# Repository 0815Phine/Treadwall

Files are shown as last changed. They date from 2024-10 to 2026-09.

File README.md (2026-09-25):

# Treadwall

A Bpod-controlled behavioral rig for head-fixed mice: the animal runs on a
treadmill while two motorized silicone "walls" move laterally to deliver
tactile stimuli that are either synchronized to running speed or driven by an
experimental protocol. A central Python GUI ([`code/treadwallGUI.py`](code/treadwallGUI.py))
launches and coordinates a whole session: dual-camera video, the Bpod state
machine, WaveSurfer data acquisition, and timestamped notes uploaded to RSpace.

<p align="center">
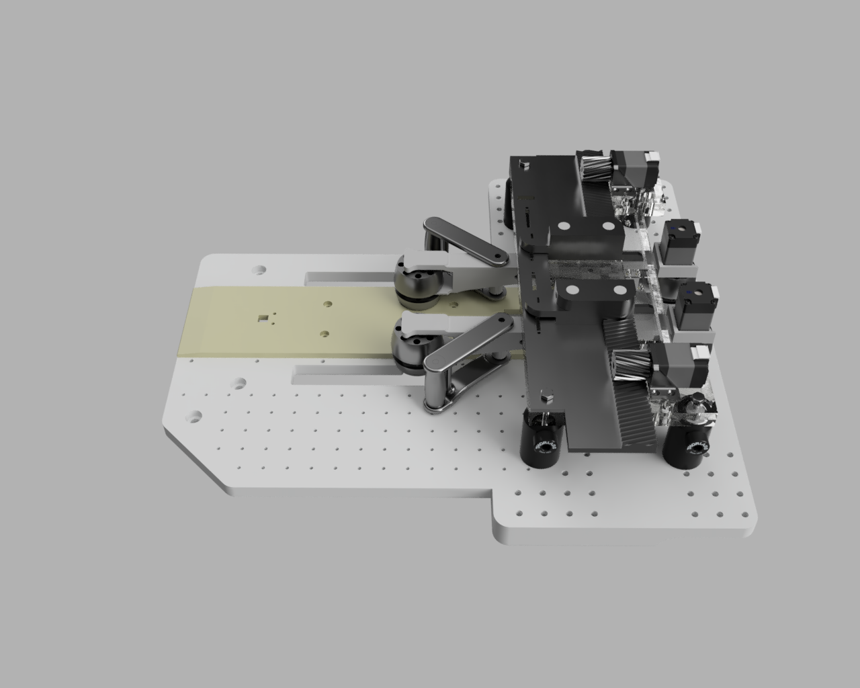
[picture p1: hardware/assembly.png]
  
</p>

This repository holds everything needed to **rebuild and run** the setup: hardware
files (3D-print STLs, laser-cut SVGs, PCB gerbers, parts lists) under
[`hardware/`](hardware/) (see the [hardware README](hardware/README.md)) and all control software under [`code/`](code/) (see the
[code README](code/README.md)).

### Repository structure

```
Treadwall/
├── hardware/            # build files + parts lists, one folder per component
│   ├── treadmillmain/       running wheel / treadmill
│   ├── treadwallmain/       moving-wall assembly (STLs, SVGs, assembly videos)
│   ├── wallsynchronizer/    Arduino + PCB that syncs wall motion to running speed
│   ├── wallmover/           PCB that drives wall position from Bpod
│   ├── circuitbox/          enclosure electronics
│   ├── assembly.png         setup overview (above)
│   └── connections_overview.png
└── code/                # see code/README.md
    ├── treadwallGUI.py      central session-launcher GUI
    ├── startsession.bat     double-click to launch
    ├── src/                 utility + GUI-helper scripts, camera, Arduino sketches
    ├── protocols/           the five Bpod experiment protocols
    ├── parameters/          central config (treadwall_config.json) + device settings
    └── dependencies/        vendored submodules (Bpod, WaveSurfer, IEECRSpace, …)
    └── gui_screenshot.png   GUI while running (see below)
```

### Getting started
1. Clone with submodules: `git clone --recurse-submodules https://github.com/0815Phine/Treadwall.git`
   (or `git submodule update --init --recursive` after a plain clone).
2. Create the `treadwall` conda environment (see [Python environment](#python-environment)).
3. Set up the IEECRSpace submodule once (see [Software Dependencies](#software-dependencies)).
4. Install **ffmpeg** and put it on `PATH` (see [Python environment](#python-environment)).
5. Edit the paths in [`code/parameters/treadwall_config.json`](code/parameters/treadwall_config.json)
   for your machine (MATLAB/Python executables, data + IPC directories).
6. Open Matlab and add the paths of wavesurfer and bpod (both found under [`code/dependencies`](code/dependencies)).
7. Launch Bpod by typing Bpod in the Matlab console and set it up (see [Bpod setup](#bpod-setup))
8. Launch a session by double-clicking [`code/startsession.bat`](code/startsession.bat)
   — see [Running a Session](#running-a-session).

## Bpod System
Control of the system is done with the Bpod System. All used modules are controlled by a 'state machine' ([sanworks.io](https://sanworks.io/shop/viewproduct?productID=1036)).

Modules used:
| Module | Link | Functionality |
| :---: | :---: | :---: |
| Analog Output Module | [sanworks.io](https://sanworks.io/shop/viewproduct?productID=1038) | loaded with Waveplayer Firmware, can play analog signals, controls lateral movement of walls |
| Analog Input Module | [sanworks.io](https://sanworks.io/shop/viewproduct?productID=1037) | reads analog signals, used for zone transition in predictable paradigm |
| Rotary Encoder Module V2 | [sanworks.io](https://sanworks.io/shop/viewproduct?productID=1034) | connected directly to the rotary encoder, provides power and sends speed information to analog input module, loaded with modified firmware ([github.com](https://github.com/0815Phine/Bpod_RotaryEncoder_Firmware)) |

For further modules see [sanworks.io/products](https://sanworks.io/shop/products.php).

### Bpod setup
On **first start** Bpod has to be configured to run properly. Therefore start the Bpod GUI by typing ```Bpod``` in the Matlab console.
All modules have to be coupled with the correct COM of your system (also check the Arduino COM in the main treadwall_config.json).
You additionally have to configure the data paths once. Use the same 'Data Root' as defined in the config file (this is not strictly needed but in case of falling back to this, it is good to match).
The 'Protocols' directory should point to [`code/protocols`](code/protocols).

## Software Dependencies
| Tool | Version / build | Purpose |
| :--- | :--- | :--- |
| MATLAB | R2024a | Runs Bpod (`Bpod_Gen2`) + WaveSurfer |
| WaveSurfer | 1.0.x (see `code/dependencies/Wavesurfer`) | Synchronized data acquisition (needs a DAQ) |
| ffmpeg ([ffmpeg.org](https://ffmpeg.org/)) | gyan.dev **full** build, on `PATH` | Live H.264 encoding in `videoacquisition.py`; full build needed for `h264_nvenc` (GPU) |
| Anaconda / Python | Python 3.11 | Runs the GUI + camera scripts (`treadwall` env) |
| Basler pylon Camera Software Suite | matching pypylon 4.1 | Camera drivers/runtime for `pypylon` |
| NI-DAQmx driver + NI DAQ device | — | WaveSurfer acquisition + TTL sync (the "DAQ-Box") |
| Pololu Tic software (Tic Control Center) | — | Configure the Wall Mover / Wall Synchronizer stepper controllers |
| Arduino IDE | 2.x ([arduino.cc](https://www.arduino.cc/en/software)) | Flash/modify the Wall-Synchronizer Arduino + rotary-encoder firmware |
| git | ≥ 2.x | Clone the repo with `--recurse-submodules` |
| PsychToolbox (*optional*) | — | **Not needed for Treadwall's default setup.** Bpod only requires it for legacy MATLAB (r2019a or older), displaying video/sound stimuli on the PC, or the legacy Bonsai UDP/TCP link — none of which Treadwall uses. Safe to keep installed if you already have it. |

### Submodules
External code is vendored as **git submodules** under [code/dependencies/](code/dependencies/).
Clone with `git clone --recurse-submodules`, or run `git submodule update --init --recursive`
after cloning.

| Submodule | Source | Notes |
| :--- | :--- | :--- |
| `Bpod_Gen2` | [sanworks/Bpod_Gen2](https://github.com/sanworks/Bpod_Gen2) @ `master` (pinned `8e5b008`, v1.9.0) | Stock Bpod control framework. |
| `Bpod_RotaryEncoder_Firmware` | [0815Phine/Bpod_RotaryEncoder_Firmware](https://github.com/0815Phine/Bpod_RotaryEncoder_Firmware) | Modified rotary-encoder module firmware (needed for the *predictable* experiments). |
| `Wavesurfer` | [JaneliaSciComp/Wavesurfer](https://github.com/JaneliaSciComp/Wavesurfer) | WaveSurfer app for synchronized data acquisition. |
| `IEECRSpace` | [IEECR-BeckGroup/IEECRSpace](https://github.com/IEECR-BeckGroup/IEECRSpace) | RSpace integration; `treadwallGUI.py` adds `IEECRSpace/src` to `sys.path` and imports `rspace`. |

**IEECRSpace must be set up once before the GUI's RSpace features work.** The submodule is a
self-contained app that installs itself on first launch. If you haven't done this yet, run its
first-time setup — on Windows double-click
[`code/dependencies/IEECRSpace/IEECRSpace_Launcher.bat`](code/dependencies/IEECRSpace/) (the first
launch downloads its own private Python + dependencies, so it needs an internet connection) — and
then paste your RSpace API key into the app's **Settings** tab. See the
[IEECRSpace README](code/dependencies/IEECRSpace/README.md) for the full instructions.

### Python environment
The GUI and camera scripts run on a dedicated conda environment pinned in
[`code/dependencies/environment.yml`](code/dependencies/environment.yml). Create it once:

```
conda env create -f code/dependencies/environment.yml
```

This builds an env named `treadwall` (Python 3.11 + numpy, opencv-python, pypylon, PyQt5,
requests). The launcher ([code/startsession.bat](code/startsession.bat)) and the camera subprocess
already point at this env's interpreter, so **the `treadwall` env must exist for the app to run**.
(`rspace` is not listed here — it is imported from the `IEECRSpace` submodule source.)

**ffmpeg** is required for live video encoding and is **not** a conda package here — the camera
calls `ffmpeg` by name, so it must be on the system `PATH`. FFmpeg's official home is
[ffmpeg.org](https://ffmpeg.org/), which doesn't ship Windows binaries itself but links trusted
builders on its [download page](https://ffmpeg.org/download.html) (→ *Windows*). Install the
**gyan.dev _full_ build**: `winget install Gyan.FFmpeg`, or download `ffmpeg-full` from
[gyan.dev/ffmpeg/builds](https://www.gyan.dev/ffmpeg/builds/), unzip, and add its `bin\` folder to
`PATH`; verify with `ffmpeg -version`. Use the *full* build (not the conda-forge one): the camera
auto-detects and prefers the `h264_nvenc` (NVIDIA GPU) encoder, which the full build ships but the
conda-forge build generally omits — otherwise capture silently falls back to CPU `libx264`.

### Arduino libraries
**Arduino libraries** are installed via the Arduino IDE **Library Manager** (the IDE resolves
libraries from its own sketchbook `libraries/` folder, not from this repo):
- `CapacitiveSensor` (PaulStoffregen) — Lickport sketches.
- `Tic` (Pololu) — Wall Synchronizer sketches.
- `Servo`, `SoftwareSerial` — ship with the Arduino IDE.

## Camera
Two Basler cameras are captured by
[`code/src/videoacquisition.py`](code/src/videoacquisition.py) via `pypylon`:
- a **top** camera (30 fps, hardware-triggered) and
- a **front** camera (200 fps).

Frames are encoded live to visually-lossless H.264 `.mp4` (per camera), preferring
the GPU `h264_nvenc` encoder and falling back to CPU `libx264`. All camera
settings — serials, resolution, exposure, fps, trigger lines, encode quality —
live in the `cameras` block of
[`code/parameters/treadwall_config.json`](code/parameters/treadwall_config.json),
with full Basler feature sets in the `.pfs` files under
[`code/parameters/camera/`](code/parameters/camera/). Each session produces, per
camera, a `.mp4`, a `_timestamps.txt` sidecar (one line per frame, `cam_ts,pc_ts`
— Basler device clock + PC `perf_counter` clock), and a `_cam_metadata.json`.

## Data acquisition
Synchronized analog/TTL signals are recorded with **WaveSurfer** over an NI-DAQ
device, using the protocol file
[`code/parameters/wavesurfer/treadwall.wsp`](code/parameters/wavesurfer/treadwall.wsp).
The Bpod state machine writes its own session `.mat`. All outputs for a session
are saved under the configured `data_root` (`paths.data_root` in
`treadwall_config.json`), organized as `<data_root>\<animal>\<session>`.

## Running a Session
Sessions are launched and coordinated from the central GUI
([`code/treadwallGUI.py`](code/treadwallGUI.py)), started by double-clicking
[`code/startsession.bat`](code/startsession.bat). The GUI orchestrates the camera,
the Bpod state machine, and WaveSurfer, and lets you take notes that upload
directly to RSpace — all without restarting MATLAB between sessions.

<p align="center">
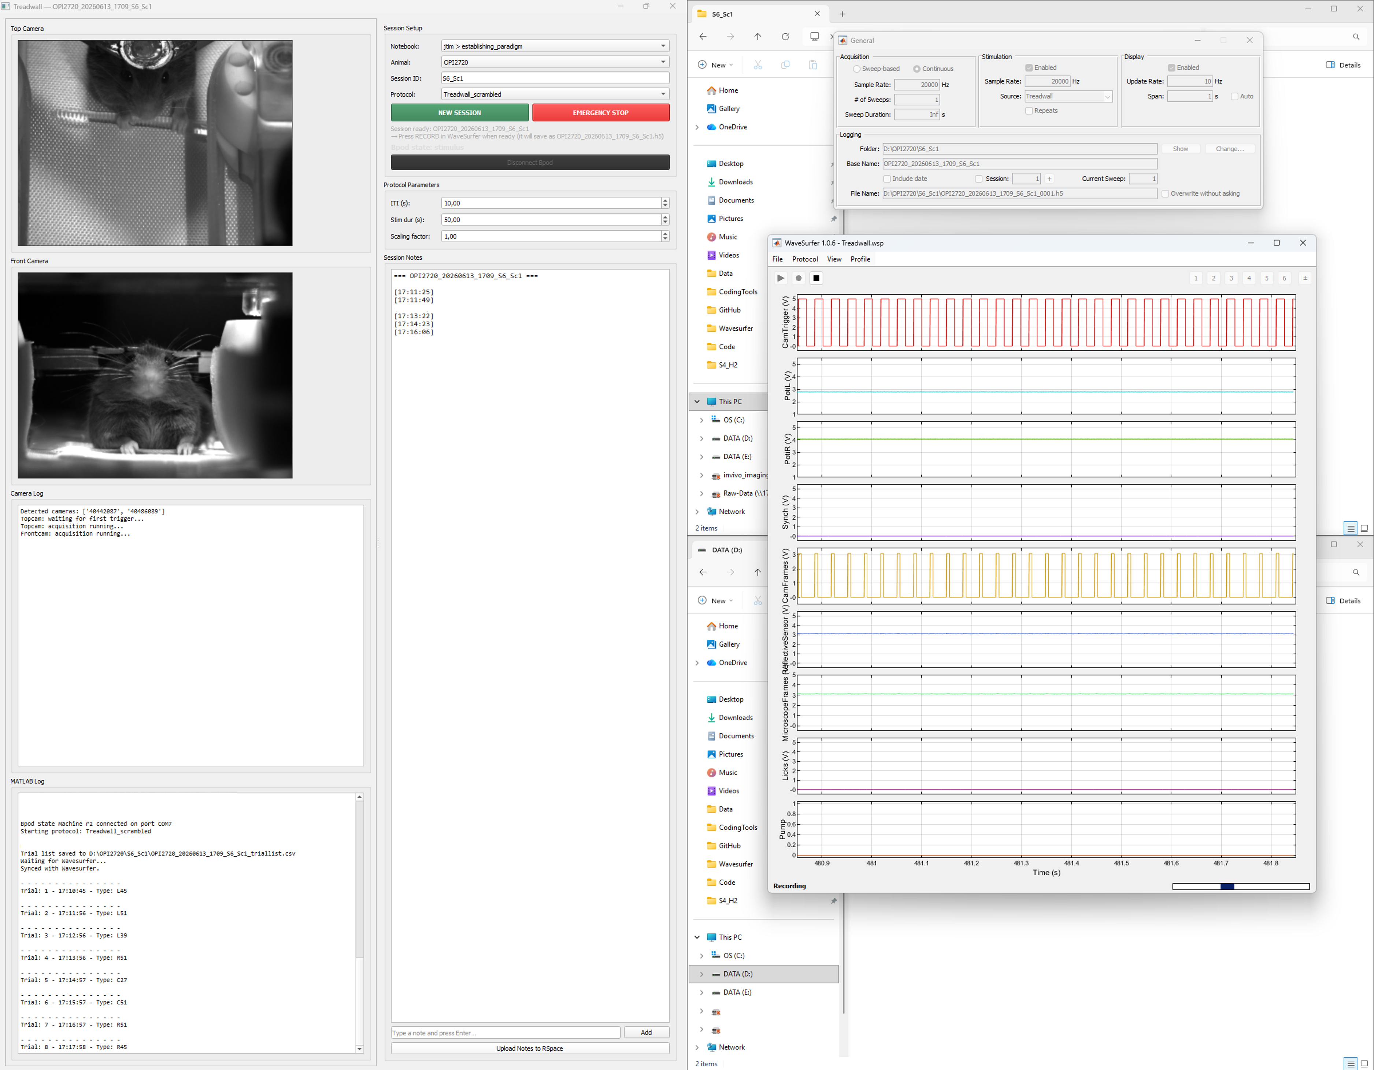
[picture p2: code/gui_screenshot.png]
  
</p>

Typical flow:
1. Double-click `startsession.bat` — the GUI opens and MATLAB starts in the
   background.
2. Pick the RSpace notebook and animal ID from the dropdowns (fetched live from
   RSpace), and choose a protocol.
3. Press **Start** — the camera preview goes live and the Bpod protocol runs.
4. Take timestamped notes during the session; they upload to RSpace.
5. The GUI auto-detects when the Bpod protocol ends, lets the camera finish
   saving, and prompts for note upload / WaveSurfer stop.

For the internals (IPC files, session helpers, multi-session loop) see the
[code README](code/README.md).

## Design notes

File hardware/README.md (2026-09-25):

# Treadwall Hardware

Build files and fabrication notes for every Treadwall component. See the
[main README](../README.md) for setup and running the rig.

## Hardware Components
- [Treadmill-Main](treadmillmain)
- [Treadwall-Main](treadwallmain)
- [Wall Synchronizer](wallsynchronizer)
- [Wall Mover](wallmover)
- [Circuit Box](circuitbox)

## Wiring Overview
<p align="center">
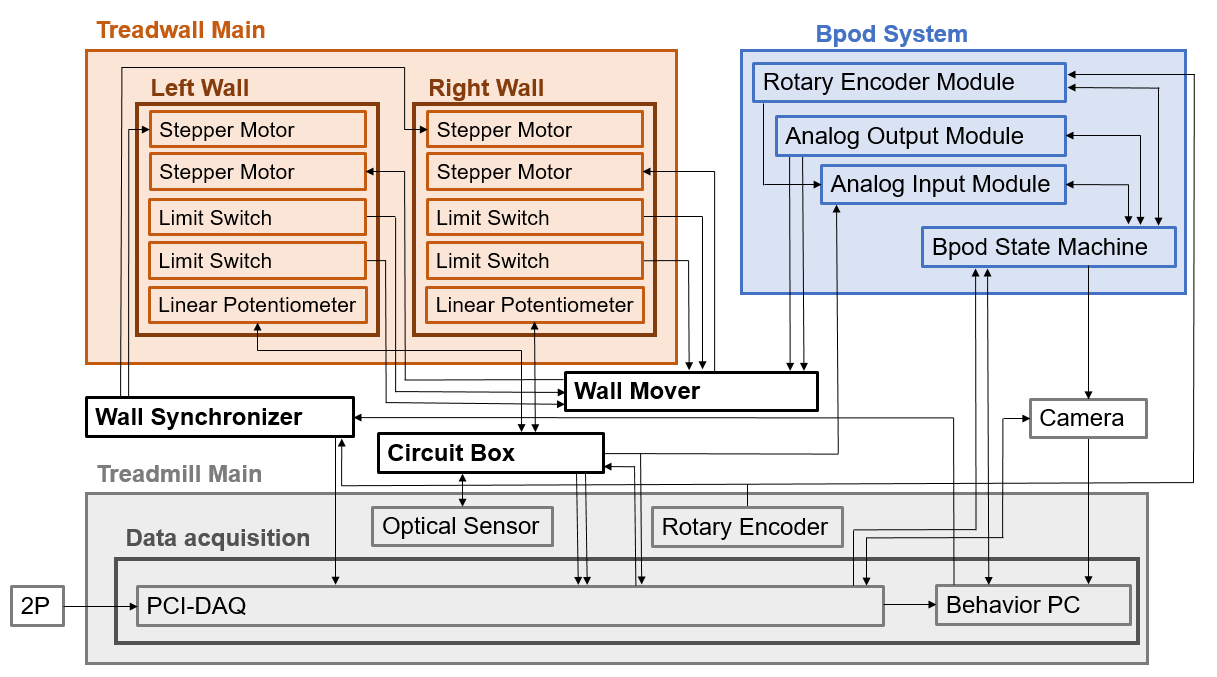
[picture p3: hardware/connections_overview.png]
  
</p>

## Lasercutting
We used a Trotec Speedy Flex lasercutter with a 100W CO2 laser with the following settings:

| Parameter | Cutting Quality | Engraving Quality |
| :---: | :---: | :---: |
| Power | 70 % | 70 % |
| Speed | 0.2 % | 3.5 % |
| Laser Source | CO2 | CO2 |
| Frequency | 20'000 Hz | 1'000 Hz |
| Passes | 1 | 1 |
| Power Correction | 10 | 10 |
| z-Offset | -2 | 0 |
| Resolution | N.A. | 500 DPI |

Red lines -> cut; black lines -> engrave; blue lines -> not assigned

## 3D Printing
All 3D-printed parts are provided as `.stl` files inside the individual
component folders, and each component's README lists them
with production amount and material (see the **File List** tables in
[Treadwall-Main](treadwallmain), [Treadmill-Main](treadmillmain),
[Wall Synchronizer](wallsynchronizer), [Wall Mover](wallmover)
and [Circuit Box](circuitbox)).

<!-- TODO: add printer model, filament/material and slicer settings once confirmed -->

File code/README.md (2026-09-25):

# Treadwall Code

All software for running the rig. A session is launched and coordinated from the
central GUI ([`treadwallGUI.py`](treadwallGUI.py)); see
[Running a Session](../README.md#running-a-session) in the top-level README for the
operator's view. This file documents the code layout and how the pieces fit
together.

## Structure

```
code/
├── treadwallGUI.py           # central PyQt5 GUI: session setup, live camera preview,
│                               notes → RSpace, protocol-parameter panel, emergency stop
├── startsession.bat          # double-click launcher (points at the treadwall conda env)
├── src/                      # utility + GUI-helper scripts
│   ├── videoacquisition.py        dual-camera capture + live H.264 encoding
│   ├── start_bpodsession.m        launches Bpod non-interactively, multi-session loop
│   ├── start_wavesurfer.m         launches / stops WaveSurfer, renames its .h5
│   ├── gui_*.m                    shared GUI↔protocol helpers (IPC dir, session init,
│   │                                param publish/read, estop timer, done signal)
│   ├── treadwall_config.m         MATLAB reader for the central JSON config
│   ├── create_triallist.m / create_zones.m / get_stimoutput.m       stimulus helpers
│   └── arduino/                   on-board firmware — see arduino/README.md
├── protocols/                # the five Bpod experiment protocols
│   ├── treadwall_baseline/    treadwall_habituation_1/   treadwall_habituation_2/
│   └── treadwall_scrambled/   treadwall_predictable/
├── parameters/               # ALL tunable settings (see below)
└── dependencies/             # vendored submodules (Bpod_Gen2, Wavesurfer, IEECRSpace,
                                  Bpod_RotaryEncoder_Firmware) — see top-level README
```

## Configuration

Everything tunable lives in
[`parameters/treadwall_config.json`](parameters/treadwall_config.json) and is read
by both sides of the rig — `treadwall_config.m` in MATLAB and `json.load(...)` in
Python. It holds machine paths, Bpod/WaveSurfer/camera settings, and GUI timing.
Edit this file (not the scripts) to retarget the rig to another machine.

Device-specific settings that don't belong in the JSON live alongside it:

| Path | What |
| :-- | :-- |
| [`parameters/bpod/`](parameters/bpod/) | Bpod protocol parameter `.m` files + a test trial list |
| [`parameters/camera/`](parameters/camera/) | Basler `.pfs` full-feature camera profiles (tunable features already listed in `treadwall_config.json`) |
| [`parameters/tics/`](parameters/tics/) | Pololu Tic stepper-controller register settings |
| [`parameters/wavesurfer/`](parameters/wavesurfer/) | WaveSurfer protocol (`treadwall.wsp`) |

The Arduino sketches are the one exception — they are compiled and flashed, so
their constants are fixed in the `#define`s at the top of each sketch. Those are
documented in [`src/arduino/README.md`](src/arduino/README.md).

## How a session runs

`startsession.bat` → `treadwallGUI.py`, which:
1. starts the camera subprocess ([`src/videoacquisition.py`](src/videoacquisition.py)),
2. launches Bpod via [`src/start_bpodsession.m`](src/start_bpodsession.m) (which
   stays alive between sessions, polling for the next one), and
3. drives WaveSurfer via [`src/start_wavesurfer.m`](src/start_wavesurfer.m).

The GUI and the MATLAB scripts coordinate through small files in the IPC directory
(`paths.ipc_dir` in the config): session hand-off, live parameter edits, emergency
stop, and end-of-session signalling. The shared `src/gui_*.m` helpers implement the
protocol side of this, so all five protocols behave consistently.

<p align="center">
  
</p>

## Requirements

Language and library versions are pinned centrally — see
[Software Dependencies](../README.md#software-dependencies) and
[Python environment](../README.md#python-environment) in the top-level README
(Python 3.11 via [`dependencies/environment.yml`](dependencies/environment.yml),
MATLAB R2024a, plus ffmpeg on `PATH`).

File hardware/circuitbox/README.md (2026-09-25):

# Circuit Box

The central enclosure that houses the shared rig electronics and routes the
connections between the Bpod system, the linear potentiometers, and the reflective/optical sensor. See the repo-level [wiring overview](../connections_overview.png) for how it ties
into the rest of the setup.

<p align="center">
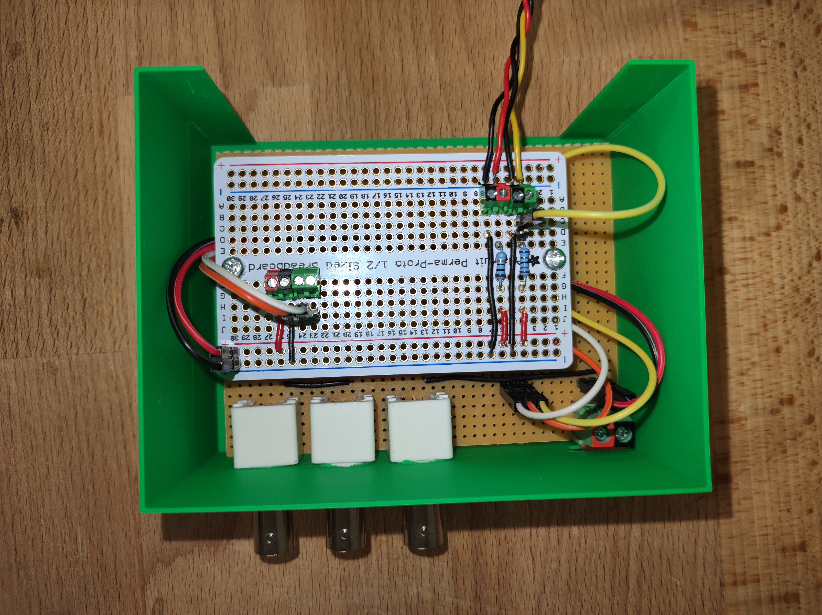
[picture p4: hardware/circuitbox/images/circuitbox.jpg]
  
</p>

### File List
| Component | Production Amount | Material | Notes |
| :---: | :---: | :---: | :---: |
| Box top | 1 piece |  | `top.stl` |
| Box bottom | 1 piece |  | `bottom.stl` |

All files are available as .stl for 3D-printing.

### Commercial Parts List
<!-- TODO: add the commercial parts list (item / quantity / notes / product link),
     matching the table format used in the wallmover and wallsynchronizer READMEs. -->

### Wiring Diagram
<!-- TODO: add the circuit-box wiring diagram / connection overview image here,
     e.g. ./images/circuitbox_connections.png -->

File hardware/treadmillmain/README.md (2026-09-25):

# Treadmill-Main

The running surface the animal sits on: a belt-driven treadmill whose rotation is
read by a rotary encoder (running speed/distance) and monitored for belt slippage
by a reflective sensor. The measured running speed drives the moving walls via the
[Wall Synchronizer](../wallsynchronizer).

### File List
| Treadwall Component | File | Production Amount | Material |
| :---: | :---: | :---: | :---: |
| Platform | [platform.stl](platform.stl) | 1 piece |  |
| Platform extention (optional) | [platfrom_extention.stl](platfrom_extention.stl) | 1 piece |  |
| Wheel | [wheel.stl](wheel.stl) | 2 pieces |  |
| Wheel gummy | [wheelgummy.stl](wheelgummy.stl) | 12 pieces |  |
| Rot Sensor Holder | [rotsensor_holder.stl](rotsensor_holder.stl) | 1 piece |  |
| Ball Bearing Holder | [ballbearing_holder.stl](ballbearing_holder.stl) | 3 pieces |  |

All files are available as .stl for 3D-printing.

### Commercial Parts List
| Item | Quantity | Notes | Product Example Link |
| :---: | :---: | :---: | :---: |
| Rotary encoder | 1 piece |  | [sanworks.io](https://sanworks.io/shop/viewproduct?productID=1307)  |
| Reflective sensor | 1 piece | to measure belt slippage | [adafruit.com](https://www.adafruit.com/product/3930?srsltid=AfmBOoqHi9kokLFhfNtaCtoBjj8dQEUZTka99oJ9M-Xgqp1RmW8L5P0L) |
| Rod | ~ | to hold wheels | [conrad.de](https://www.conrad.de/de/p/silberstahl-welle-reely-o-x-l-6-mm-x-500-mm-237086.html) |
| Shaft Colar | 7 pieces | to fix wheels on rod | [conrad.de](https://www.conrad.de/de/p/famotec-stellring-sortiment-passend-fuer-welle-details-6-mm-m3-10-st-2106638.html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) |
| Ball Bearings | 3 pieces |  | [conrad.de](https://www.conrad.de/de/p/reely-hk-0608-nadelhuelse-6-mm-10-mm-8-mm-217042.html) |
| Aluprofile | ~ |  | [thorlabs.com](https://www.thorlabs.com/newgrouppage9.cfm?objectgroup_id=194) |
| Belt | ~2m long |  | from [Luigs & Neumann](https://www.luigs-neumann.org/) (Part number: 700-100 900 0201) |

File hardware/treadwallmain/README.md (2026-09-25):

# Treadwall-Main

The moving-wall assembly: two silicone bands ("walls") on either side of the
animal, each driven laterally by a rack-and-pinion stepper stage and kept taut by
a tensioner. The walls provide the tactile stimulus that moves relative to
the animal during an experiment.

<p align="center">
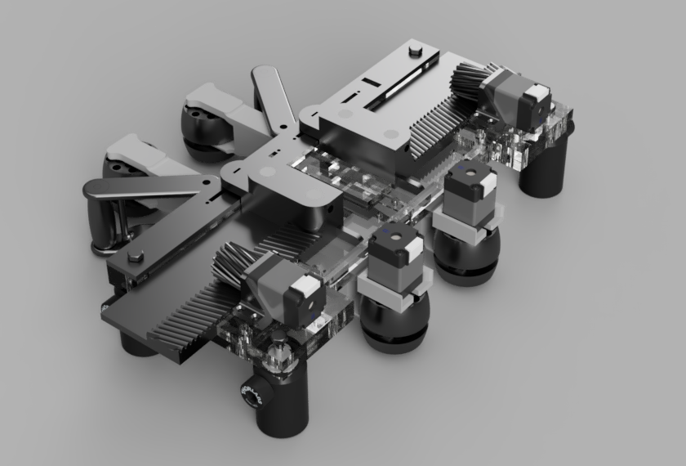
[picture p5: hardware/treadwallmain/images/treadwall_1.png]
  
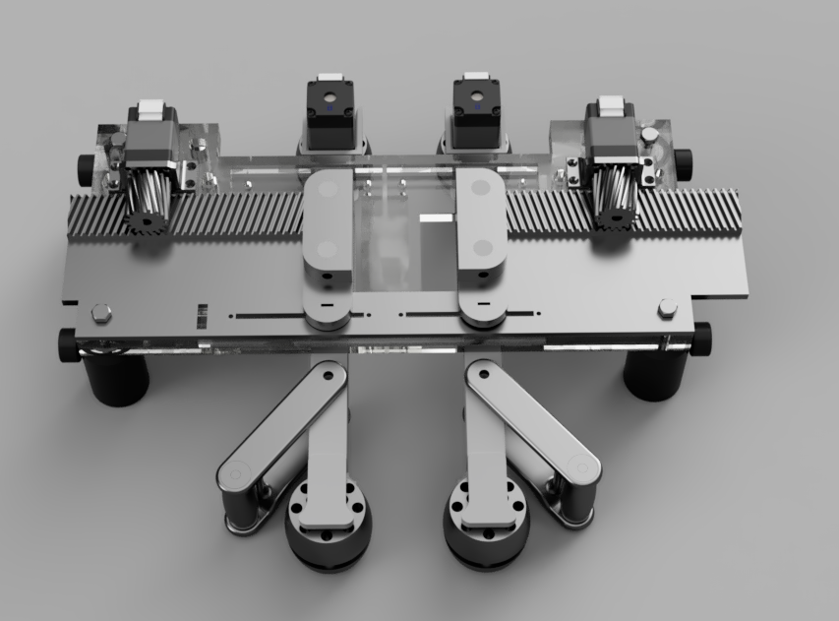
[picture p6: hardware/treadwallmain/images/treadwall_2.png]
  
</p>

### Assembly

Full-rig assembly
([download](./images/treadwall_assembly.mp4) if the player does not load):

<video src="https://github.com/0815Phine/Treadwall/raw/main/hardware/treadwallmain/images/treadwall_assembly.mp4" controls width="800"></video>

Wall assembly
([download](./images/wall_assembly.mp4)):

<video src="https://github.com/0815Phine/Treadwall/raw/main/hardware/treadwallmain/images/wall_assembly.mp4" controls width="800"></video>

### File List
| Treadwall Component | File | Production Amount | Material | Notes |
| :---: | :---: | :---:  | :---: | :---: |
| Guidingplater topper | [cutlines.svg](guidingplate_topper_cutlines.svg) | 1 piece | Acrylic glass 3mm | cut with lasercutter |
| Guidingplate top | [cutlines.svg](guidingplate_top_cutlines.svg) ([measurments](guidingplate_top_measurments.pdf)) | 1 piece | Acrylic glass 6mm | cut with lasercutter |
| Guidingplate bottom | [cutlines.svg](guidingplate_bottom_cutlines.svg) ([measurements](gguidingplate_bottom_measuremnets.pdf)) | 1 piece | Acrylic glass 6mm | cut with lasercutter |
| Walls | [wall.stl](wall.stl) | 2 pieces |  | without tensioner attachement |
| Wall-band |  | 2 pieces | Silicone | use mould ([wallband_mould.stl](wallband_mould.stl)) and buck ([wallband_buck.stl](wallband_buck.stl)) |
| Tensioner holder | [tension_holder.stl](tension_holder.stl) | 2 pieces |  |  |
| Tensioner roller | [tension_roller.stl](tension_roller.stl) | 2 pieces |  |  |
| Motorized roller | [roller_motorized.zip](roller_motorized.zip) | 2 pieces |  | only top and bottom part need to be printed |
| Passive roller | [roller_passive.zip](roller_passive.zip) | 2 pieces |  | only top and bottom part need to be printed |
| Rack left | [rack_left.stl](rack_left.stl) | 1 piece |  |  |
| Rack right | [rack_right.stl](rack_right.stl) | 1 piece |  |  |
| Pinion gear left | [piniongear_left.stl](piniongear_left.stl) | 1 piece |  |  |
| Pinion gear right | [piniongear_right.stl](piniongear_right.stl) | 1 piece |  |  |
| Motor mount | [motormount_v2.stl](motormount_vr.stl) | 2 pieces |  |  |
| Heat sink | [measurments](motormount_v1.pdf) | 2 pieces | metal | old motor mount, fabricated with CNC-machine |

All files are available as .stl for 3D-printing. Cutlines for lasercutting are available as .svg

### Commercial Parts List
| Item | Quantity | Notes | Product Example Link |
| :---: | :---: | :---: | :---: |
| Stepper motor | 2 pieces | for Synchronizer, 3.9V, 0.6A/Phase | [pololu.com](https://www.pololu.com/product/1204) |
| Stepper motor | 2 pieces | for Mover, 4.3V, 0.8A/Phase | [pololu.com](https://www.pololu.com/product/2256) |
| Sensor plug-in connector | 4 pieces | 4 poles, M8, optional, for open motor cable ends | [conrad.de](https://www.conrad.de/de/p/phoenix-contact-1441037-sensor-aktor-steckverbinder-unkonfektioniert-m8-stecker-gerade-polzahl-4-1-st-589885.html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) |
| Extension cable | 4 pieces | 4 poles, M8, optional | [conrad.de](https://www.conrad.de/de/p/bkl-electronic-2700038-sensor-aktor-verlaengerungsleitung-m8-stecker-gerade-auf-kupplung-gerade-2-m-polzahl-4-1-st-2807268.html) |
| Limit switch | 4 pieces |  | [rs-online.com](https://de.rs-online.com/web/p/mikroschalter/6821500) |
| Linear Potentiometer | 2 pieces | to read position of each wall | [digikey.de](https://www.digikey.de/de/products/detail/alps-alpine/RS45111A900F/19529172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) |
| Bearings | 10 pieces | 4 mm inner diameter, 12 mm outer diameter | [kugellager-express.de](https://www.kugellager-express.de/miniatur-kugellager-604-zz-4x12x4-mm) |
| Post Holder | 4 pieces | Partnumber: UPH30/M, adaptable | [thorlabs.com](https://www.thorlabs.com/newgrouppage9.cfm?objectgroup_id=1982) |
| Post | 4 pieces | Partnumber: TR30/M, adaptable | [thorlabs.com](https://www.thorlabs.com/newgrouppage9.cfm?objectgroup_id=1266) |
| Dovel | 2 pieces | 32x4mm, for passive roller |  |
| Dovel | 2 pieces | 20x4mm, for motorized roller |  |
| Dovel | 4 pieces | for attaching wall to rack |  |
| Screw | 2 pieces | M4 40mm |  |
| Screw | 8 pieces | M4 20mm |  |
| Screw | 8 pieces | M2 20mm |  |
| Nut | 10 pieces | M4 |  |
| Nut | 8 pieces | M2 |  |

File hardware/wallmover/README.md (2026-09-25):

# Wall Mover

<p align="center">
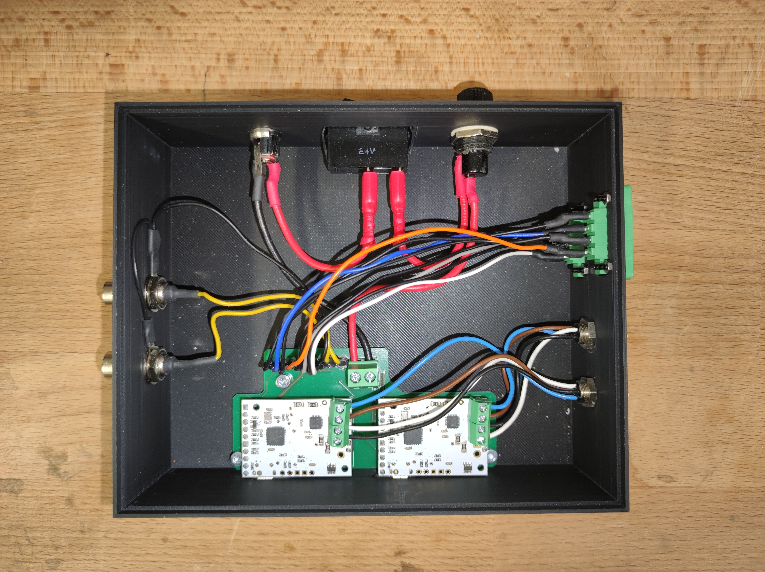
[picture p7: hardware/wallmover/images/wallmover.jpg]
  
</p>

| Item | Quantity | Notes | Product Example Link |
| :---: | :---: | :---: | :---: |
| Motor controller | 2 pieces |  | [pololu.com](https://www.pololu.com/product/3132) |
| Sensor connector | 2 pieces | M8, 4-poles, stepper motor input | [conrad.de](https://www.conrad.de/de/p/conec-42-01001-sensor-aktor-einbausteckverbinder-m8-buchse-einbau-polzahl-4-1-st-714987.html) |
| Klemmenblock | 2 pieces | 4-pole connector, limit switch input, have to be modified to screw into box |  |
| Klemmenblock-Steckverbinder | 2 pieces | attachted to limit switch cabled |  |
| BNC Connector | 2 piece | with mounting hardware, bpod system input | [digikey.com](https://www.digikey.de/de/products/detail/amphenol-rf/31-221-RFX/100648) |
| Power connector | 1 piece | power input | [reichelt.de](https://www.reichelt.de/de/de/shop/produkt/einbaubuchse_zentraleinbau_aussen_5_6_mm_innen_2_5_mm-8525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) |
| Fuse | 1 piece |  | [conrad.de](https://www.conrad.de/de/p/tru-components-tc-r3-12-sicherungshalter-passend-fuer-sicherungen-feinsicherung-5-x-20-mm-10-a-250-v-ac-1-st-1587496.html), [conrad.de](https://www.conrad.de/de/p/eska-522-716-522716-feinsicherung-o-x-l-5-mm-x-20-mm-0-8-a-250-v-traege-t-inhalt-10-st-524346.html) |
| Switch | 1 piece |  |[ conrad.de](https://www.conrad.de/de/p/a12131121000-wippschalter-a12131121000-250-v-ac-10-a-1-x-aus-ein-rastend-1-st-701661.html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) |
| Power supply cable | 1 piece | Output: 12V--3A | [conrad.de](https://www.conrad.de/de/p/mean-well-gst36e12-p1j-steckernetzteil-festspannung-12-v-dc-3000-ma-36-w-1439200.html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) |
| Nut M8x0.5 | 2 pieces | to attach 4-pole sensor connectors |  |
| Nut M | 4 pieces| to secure 4-pole Klemmenblock |  |
| Screw M | 4 pieces | to secure 4-pole Klemmenblock |  |
| Leiterplatte |  | 2.54mm Raster, needed if soldering PCB yourself | [conrad.de](https://www.conrad.de/de/p/tru-components-su527629-europlatine-hartpapier-l-x-b-90-mm-x-50-mm-35-m-rastermass-2-54-mm-inhalt-1-st-1570117.html) |
| Stiftleiste | 11 poles | to solder on Cables | [conrad.de](https://www.conrad.de/de/p/tru-components-stiftleiste-standard-anzahl-reihen-1-polzahl-je-reihe-36-1581019-1-st-1581019.html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) |
| Buchsenleiste | 11 poles | to solder on PCB | [conrad.de](https://www.conrad.de/de/p/tru-components-buchsenleiste-standard-anzahl-reihen-1-polzahl-je-reihe-36-1580960-1-st-1580960.html) |
| Terminal Block | 1 piece | to solder on PCB, power supply |  |
| Wire set |  |  | [conrad.de](https://www.conrad.de/de/p/quadrios-22cw002-litzensortiment-1-x-0-25-mm-weiss-blau-braun-orange-gruen-gelb-grau-violett-schwarz-rot-1-set-2620404.html) |
| Shrinktube |  |  | [conrad.de](https://www.conrad.de/de/p/dsg-canusa-8640015953-schrumpfschlauch-ohne-kleber-schwarz-1-60-mm-0-80-mm-schrumpfrate-3-1-10-m-708870.html) |

### Wiring Diagram
<p align="center">
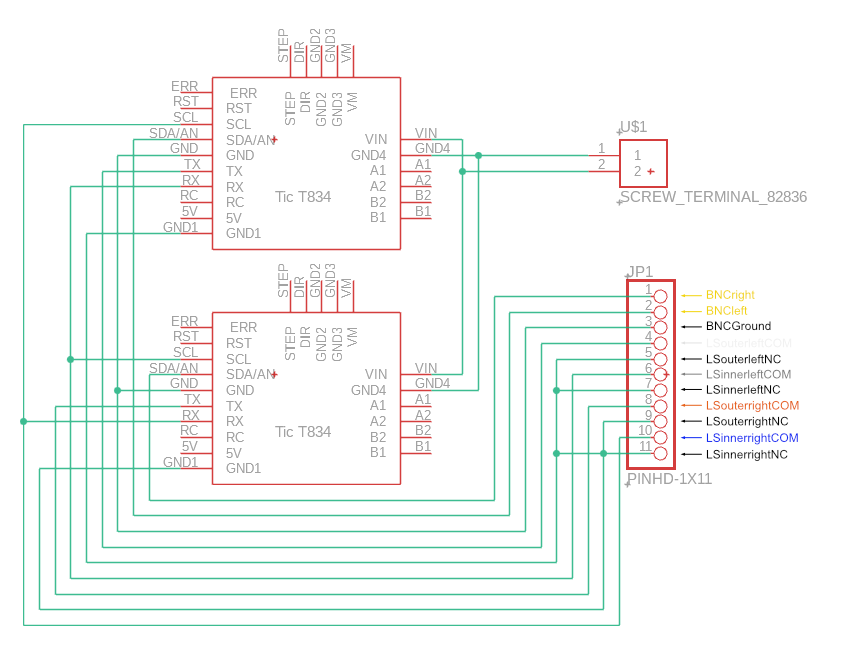
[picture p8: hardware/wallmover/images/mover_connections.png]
  
</p>

### PCB
<p align="center">
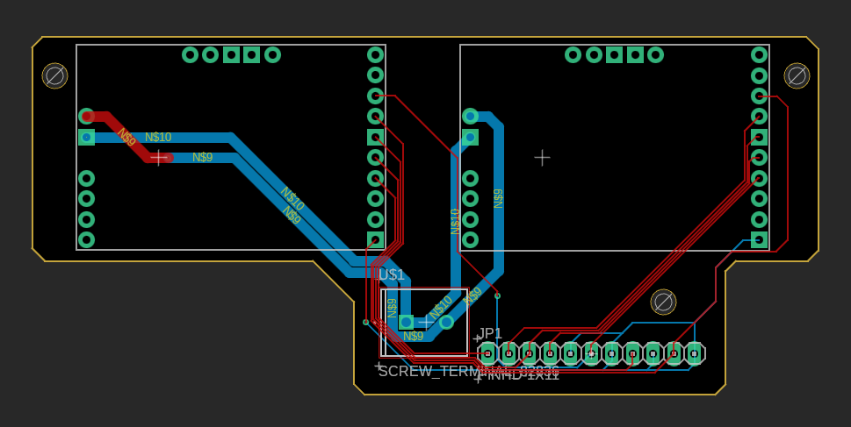
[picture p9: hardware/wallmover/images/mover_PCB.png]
  
</p>

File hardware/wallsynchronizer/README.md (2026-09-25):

# Wall Synchronizer

<p align="center">
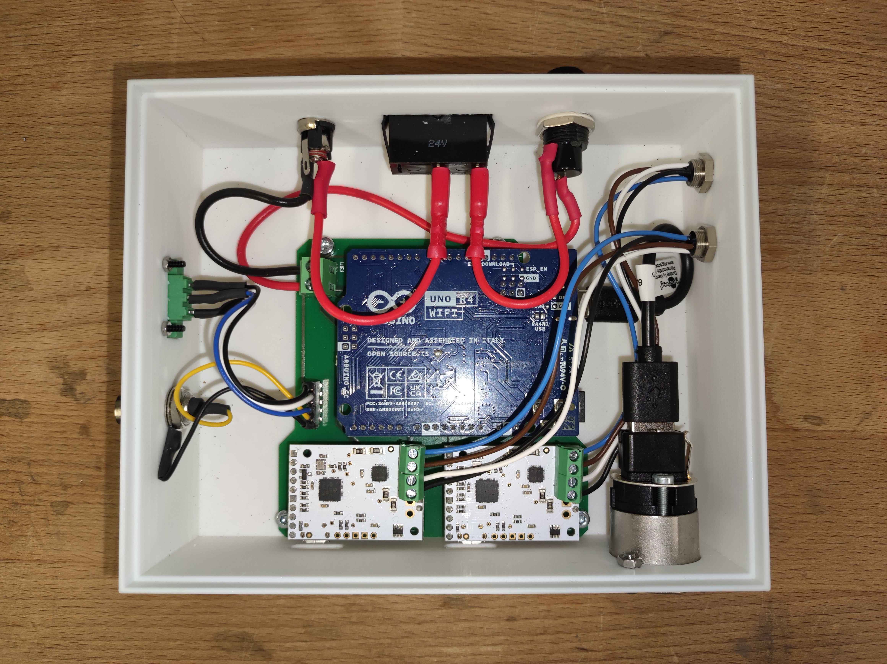
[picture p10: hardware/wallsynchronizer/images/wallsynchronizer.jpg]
  
</p>

| Item | Quantity | Notes | Product Example Link |
| :---: | :---: | :---: | :---: |
| Arduino Uno | 1 piece |  | [arduino.cc](https://store-usa.arduino.cc/products/uno-r4-minima) |
| Motor Controller | 2 pieces |  | [pololu.com](https://www.pololu.com/product/3132) |
| Sensor Connector | 2 pieces | M8, 4-poles, stepper motor input | [conrad.de](https://www.conrad.de/de/p/conec-42-01001-sensor-aktor-einbausteckverbinder-m8-buchse-einbau-polzahl-4-1-st-714987.html) |
| Klemmenblock | 1 piece | 3-poles, rotary encoder input |  |
| Klemmenblock-Steckverbinder | 1 piece | 3-poles, fixed to rotary encoder cables |  |
| BNC connector | 1 piece | for speed readout, pwm signal | [rs-online.com](https://de.rs-online.com/web/p/koaxial-steckverbinder/2478704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) |
| Coding connector | 1 piece |  | [conrad.de](https://www.conrad.de/de/p/reversible-usb-durchfuehrung-2-0-buchse-einbau-nausb-w-durchfuehrung-nausb-w-neutrik-inhalt-1-st-746647.html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) |
| Power connector | 1 piece |  | [reichelt.de](https://www.reichelt.de/de/de/shop/produkt/einbaubuchse_zentraleinbau_aussen_5_6_mm_innen_2_5_mm-8525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) |
| Fuse | 1 piece |  | [conrad.de](https://www.conrad.de/de/p/tru-components-tc-r3-12-sicherungshalter-passend-fuer-sicherungen-feinsicherung-5-x-20-mm-10-a-250-v-ac-1-st-1587496.html), [conrad.de](https://www.conrad.de/de/p/eska-522-716-522716-feinsicherung-o-x-l-5-mm-x-20-mm-0-8-a-250-v-traege-t-inhalt-10-st-524346.html) |
| Switch | 1 piece |  | [ conrad.de](https://www.conrad.de/de/p/a12131121000-wippschalter-a12131121000-250-v-ac-10-a-1-x-aus-ein-rastend-1-st-701661.html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) |
| USB-A to USB-C cable | 1 piece | coding cable, inside box | [conrad.de](https://www.conrad.de/de/p/goobay-38675-usb-c-auf-usb-a-2-0-ladekabel-high-speed-15w-3a-5v-handy-kabel-480-mbits-adapterkabel-schwarz-0-1-m-811278356.html) |
| Power supply cable | 1 piece | Output: 12V--3A | [conrad.de](https://www.conrad.de/de/p/mean-well-gst36e12-p1j-steckernetzteil-festspannung-12-v-dc-3000-ma-36-w-1439200.html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) |
| Nut | 2 pieces | M8x0.5, to secure sensor connectors |  |
| Nut | 2 pieces| to secure 3-pole Klemmenblock |  |
| Screw | 2 pieces | to secure 3-pole Klemmenblock |  |
| Leiterplatte |  | needed if soldering PCB yourself | [conrad.de](https://www.conrad.de/de/p/tru-components-su527629-europlatine-hartpapier-l-x-b-90-mm-x-50-mm-35-m-rastermass-2-54-mm-inhalt-1-st-1570117.html) |
| Stiftleiste | 5 poles | to solder on Cables | [conrad.de](https://www.conrad.de/de/p/tru-components-stiftleiste-standard-anzahl-reihen-1-polzahl-je-reihe-36-1581019-1-st-1581019.html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) |
| Buchsenleiste | 5 poles | to solder on PCB | [conrad.de](https://www.conrad.de/de/p/tru-components-buchsenleiste-standard-anzahl-reihen-1-polzahl-je-reihe-36-1580960-1-st-1580960.html) |
| Terminal Block | 1 piece | to solder on PCB, power supply |  |
| Wire set |  |  | [conrad.de](https://www.conrad.de/de/p/quadrios-22cw002-litzensortiment-1-x-0-25-mm-weiss-blau-braun-orange-gruen-gelb-grau-violett-schwarz-rot-1-set-2620404.html) |
| Shrinktube |  |  | [conrad.de](https://www.conrad.de/de/p/dsg-canusa-8640015953-schrumpfschlauch-ohne-kleber-schwarz-1-60-mm-0-80-mm-schrumpfrate-3-1-10-m-708870.html) |

### Wiring Diagram
<p align="center">
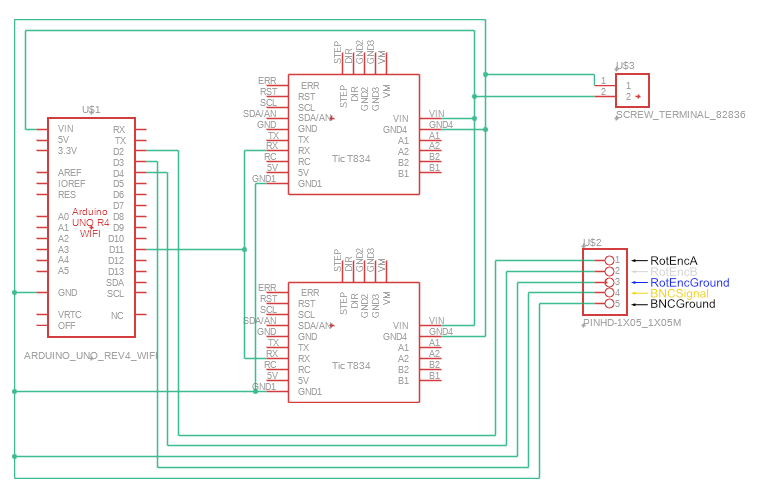
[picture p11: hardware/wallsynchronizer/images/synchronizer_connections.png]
  
</p>

### PCB
<p align="center">
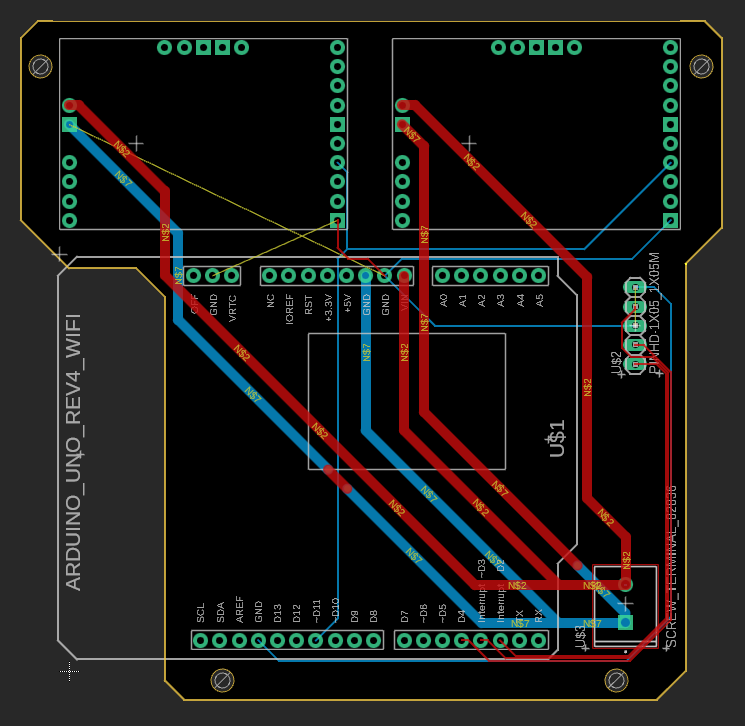
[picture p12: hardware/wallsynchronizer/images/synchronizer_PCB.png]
  
</p>

**Caution:** The Rotary Encoder will get power from the Bpod-Rotary-Encoder-Module. Power has to be provided differently if not using the Bpod-System.

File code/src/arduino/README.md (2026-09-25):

# Treadwall Arduino firmware

Two Arduino sketches drive the rig hardware:

- [`wallsynchronizer/wallsynchronizer.ino`](wallsynchronizer/wallsynchronizer.ino) — reads the
  rotary encoder, drives the two Pololu Tic stepper controllers, and streams speed as an analog
  signal so the moving wall tracks the animal's running speed.
- [`lickport/lickport.ino`](lickport/lickport.ino) — detects licks with a capacitive sensor,
  measures running distance from the encoder, and dispenses reward via a pump.

### Why these parameters aren't in `treadwall_config.json`

Everything in the rest of the rig reads its tunable parameters from
[`../../parameters/treadwall_config.json`](../../parameters/treadwall_config.json) (via
`treadwall_config.m` in MATLAB and `json.load(...)` in Python). **The Arduino sketches cannot.**
They are compiled to C++ and flashed onto the microcontroller, which has no filesystem and never
reads the JSON at runtime. The constants below are therefore fixed in the `#define`s at the top of
each sketch by design.

**Changing any value here requires editing the sketch and re-flashing the board.**

The Bpod-side serial link to these boards *is* configured centrally — see the
`bpod.arduino` block (`com`, `baud`) in `treadwall_config.json`.

## `wallsynchronizer.ino` fixed parameters

| Constant | Value | Meaning |
|---|---|---|
| `tic_serial` pins | 10 (RX), 11 (TX) | SoftwareSerial to the Tic drivers (pin 10 ← Driver TX, pin 11 → Driver RX) |
| `tic1`, `tic2` device numbers | 14, 15 | Tic serial device IDs (left / right) |
| `ANALOG_DATA_STREAM_PIN` | `A0` | Analog speed output pin |
| `ENC_A_PIN`, `ENC_B_PIN` | 2, 4 | Rotary encoder channels A / B |
| `SPEED_PIN` | 3 | PWM speed output pin (not active) |
| `RUNNING_TIMEOUT` | 5000 µs (5 ms) | Idle time before the wall is treated as stopped (compared against a `micros()` delta, so the unit is microseconds) |
| `MAX_RUNNING_SPEED` | 1 m/s | Speed clamp (min = −1 m/s) |
| `MAX_PWM_VALUE` | 4095 | PWM count for 5 V (12-bit) |
| `PWM_BASELINE` | 2045 | Idle/neutral PWM value |
| `N_STEPS` | 1024 | Rotary encoder steps per rotation |
| `STEPS_PER_REVOLUTION` | 200 | Stepper motor steps per revolution |
| `MICROSTEPS_PER_STEP` | 2 | Stepper driver microstepping |
| `WALL_WHEEL_CIRCUMFERENCE` | 109 mm | Roller wheel circumference |
| `WHEEL_RADIUS` | 53 mm | Running wheel radius |
| Encoder interrupt edge | `RISING` | `attachInterrupt` trigger edge |
| `TIC_REARM_INTERVAL_MS` | 500 ms | How often both Tics are re-energized / taken out of safe start so hardware power-up order and mid-session driver power-cycles don't matter |
| `BAUD` | 115385 | Both the Tic link and the USB serial baud rate |
| `ANRES` | 12 | Analog resolution (only needed if speed is read out via analog pin) |

Pololu Tic controller register settings (current limit, accel, step mode, etc.) live separately in
[`../../parameters/tics/`](../../parameters/tics/) and are loaded onto the Tics with the Pololu Tic
utility, not by this sketch.

## `lickport.ino` fixed parameters

| Constant | Value | Meaning |
|---|---|---|
| `LICK_OUT` | 12 | TTL lick output pin |
| `ENC_A_PIN`, `ENC_B_PIN` | 2, 4 | Rotary encoder channels A / B |
| `PUMP` | 3 | Reward pump output pin |
| `CLEAN` | 13 | Pump-cleaning input pin |
| Capacitive sensor pins | 7, 8 | `CapacitiveSensor(7, 8)` (10 MΩ resistor; antenna on pin 8) |
| `MIN_DIST` | 150 mm | Minimum distance run before reward is eligible |
| `MIN_PROB` | 70 % | Minimum probability to deliver reward |
| `N_STEPS` | 1024 | Rotary encoder steps per rotation |
| `WHEEL_RADIUS` | 53 mm | Running wheel radius |
| `SENRES` | 80 | Sensor sample count |
| `LICKTH` | 1000 | Raw capacitance above which a lick sample counts |
| `CSTH` | 3800 | Cumulative capacitance that triggers a lick event |
| `LICKTTLOUT` | 1 ms | `LICK_OUT` HIGH duration |
| `PUMPONDUR` | 3 ms | `PUMP` HIGH duration per reward |
| Encoder interrupt edge | `RISING` | `attachInterrupt` trigger edge |
| `BAUD` | 9600 | USB serial baud rate |

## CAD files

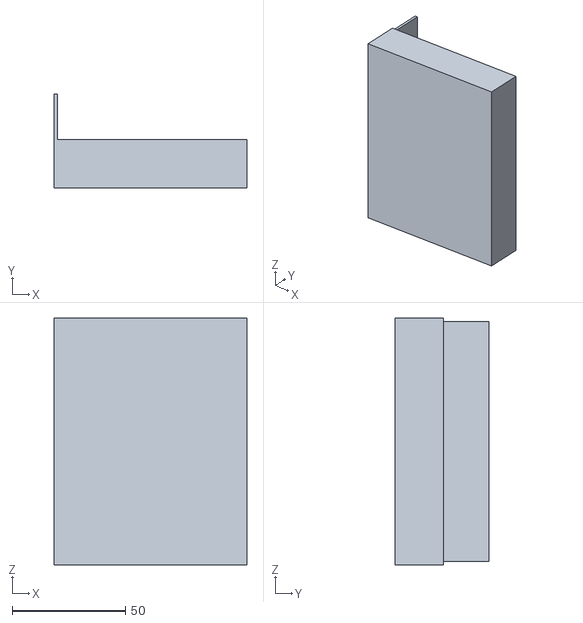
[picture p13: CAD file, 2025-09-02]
hardware/circuitbox/top.stl
85.0 x 41.5 x 109.0

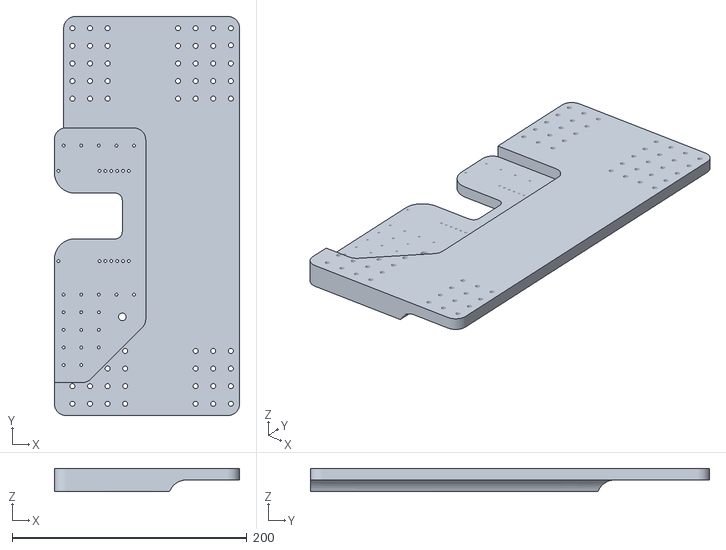
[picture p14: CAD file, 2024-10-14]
hardware/treadmillmain/platform_extention.stl
157.9 x 340.0 x 20.0

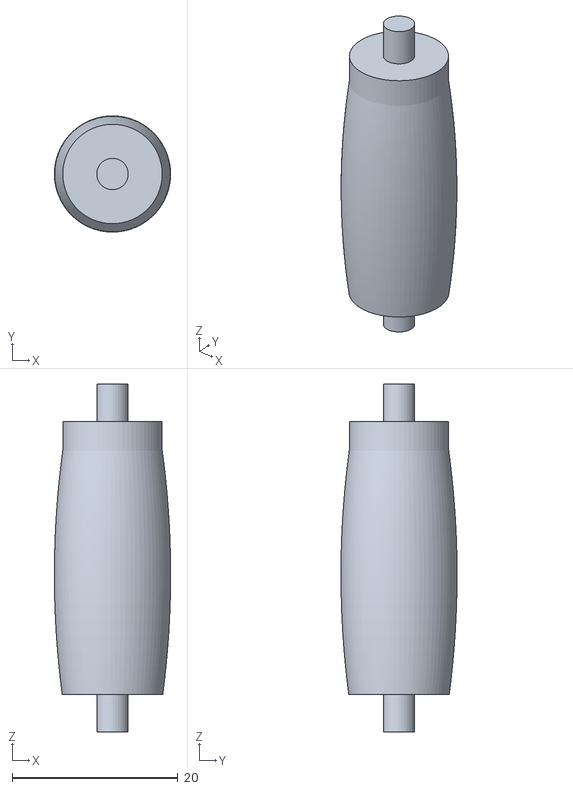
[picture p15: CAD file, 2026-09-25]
hardware/treadwallmain/tension_roller.stl
14.0 x 14.0 x 42.0

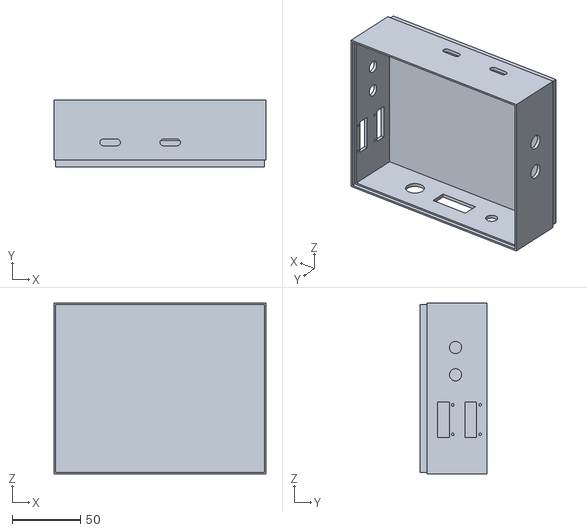
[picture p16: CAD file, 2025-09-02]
hardware/wallmover/moverbox.stl
155.0 x 49.0 x 125.0

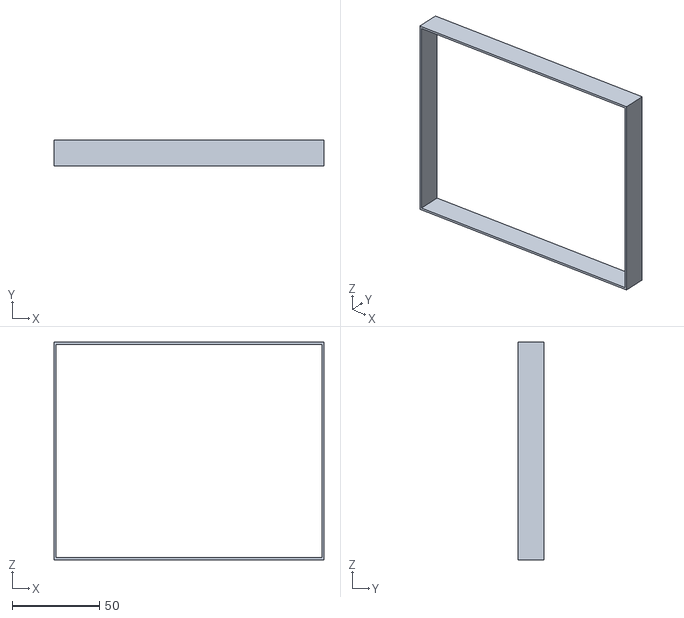
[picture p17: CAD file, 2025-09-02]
hardware/wallsynchronizer/substructure.stl
155.0 x 15.0 x 125.0

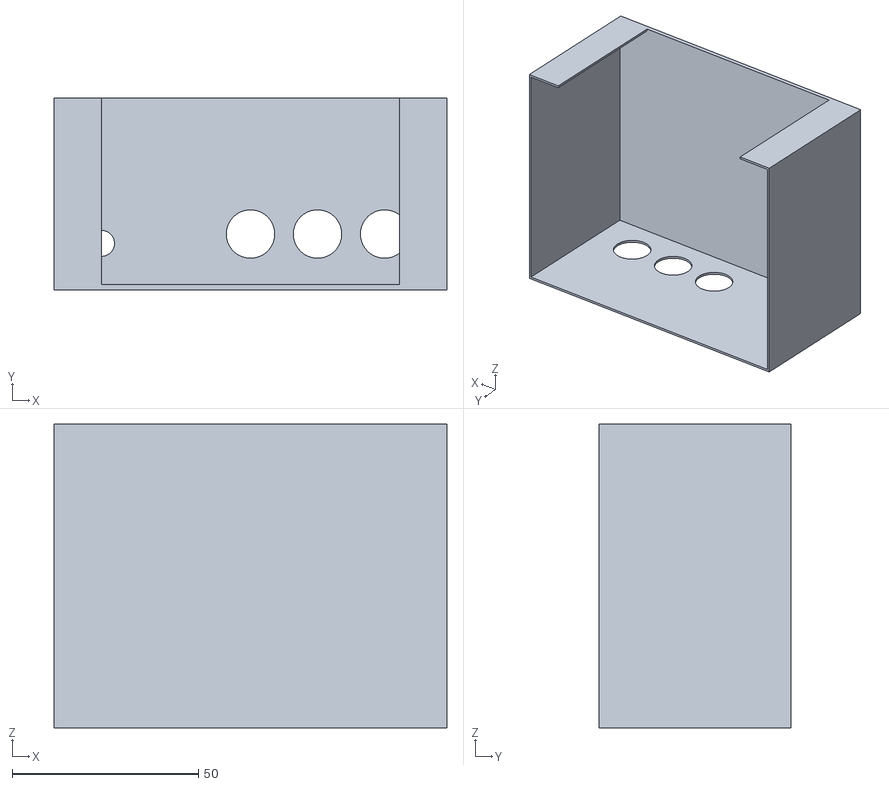
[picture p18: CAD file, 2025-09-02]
hardware/circuitbox/bottom.stl
105.5 x 51.5 x 81.5

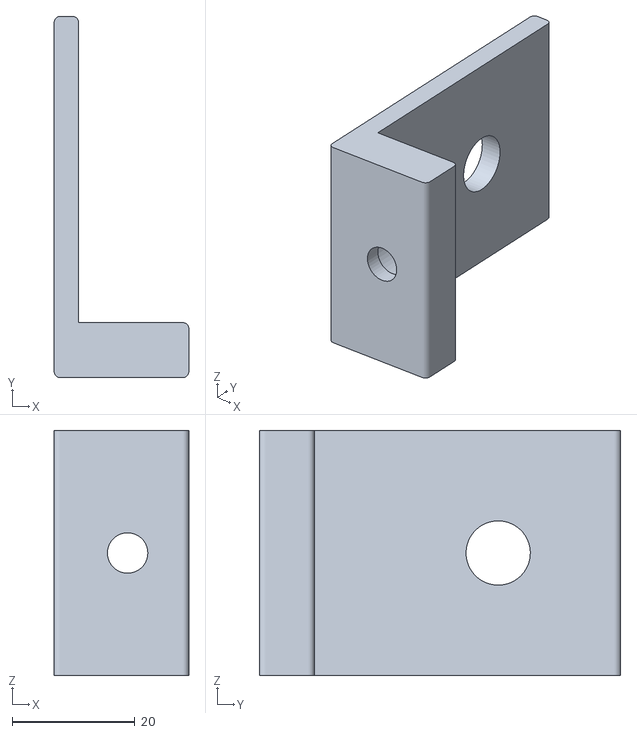
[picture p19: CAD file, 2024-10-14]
hardware/treadmillmain/ballbearing_holder.stl
22.0 x 59.0 x 40.0

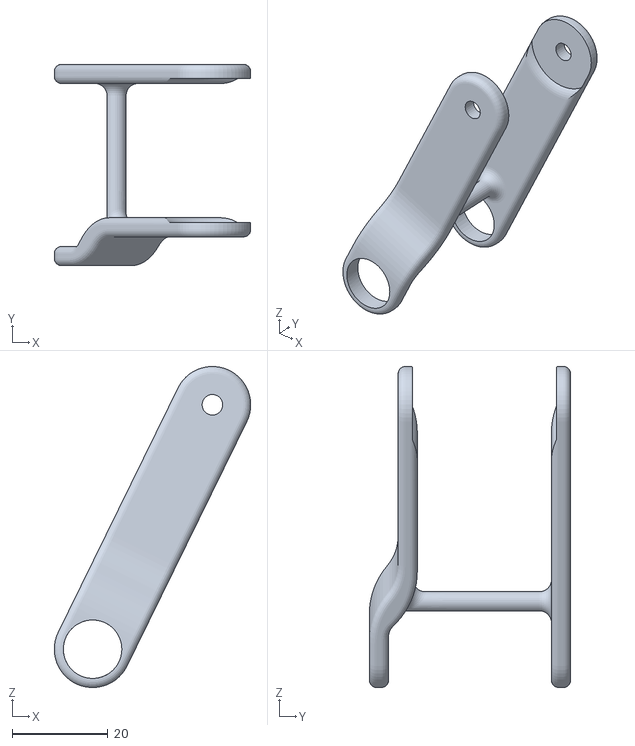
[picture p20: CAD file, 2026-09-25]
hardware/treadwallmain/tension_holder.stl
41.0 x 42.0 x 67.0

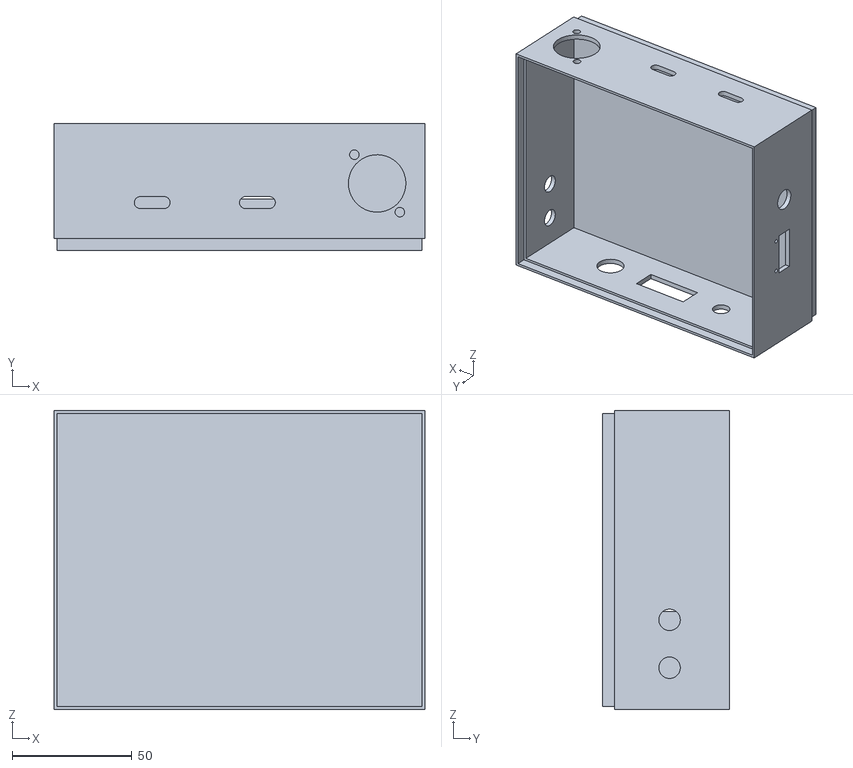
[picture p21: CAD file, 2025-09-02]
hardware/wallsynchronizer/synchronizerbox.stl
155.0 x 53.0 x 125.0

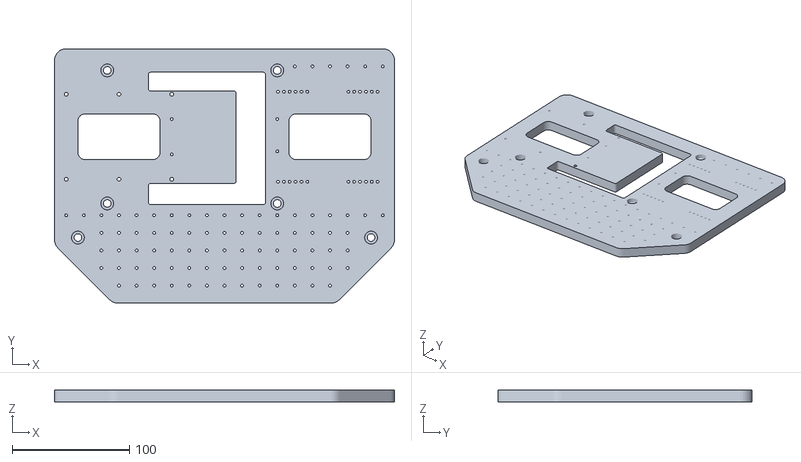
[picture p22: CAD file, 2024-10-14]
hardware/treadmillmain/platform.stl
290.0 x 217.0 x 10.0

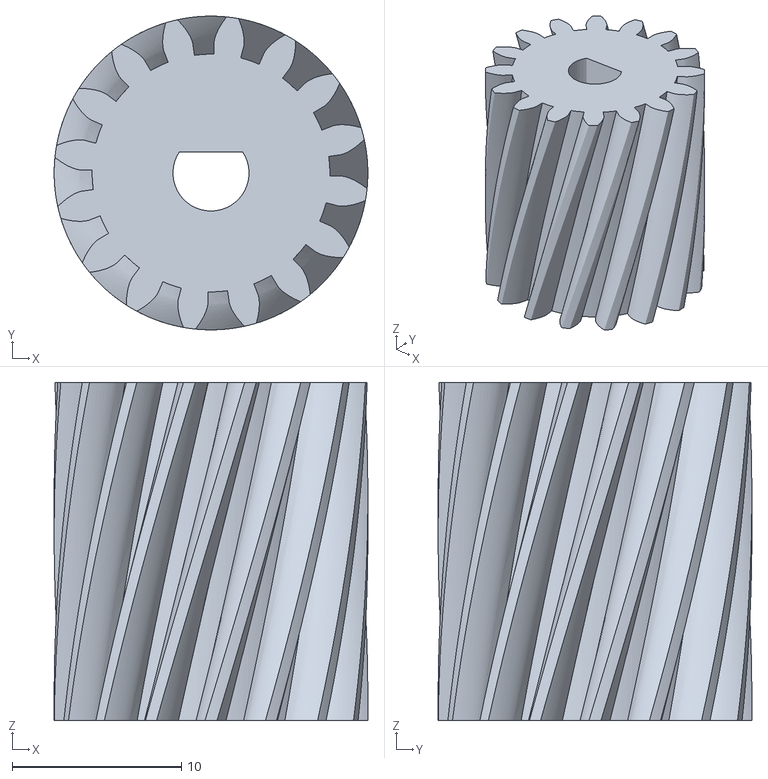
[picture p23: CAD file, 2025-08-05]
hardware/treadwallmain/piniongear_right.stl
18.6 x 18.6 x 20.0

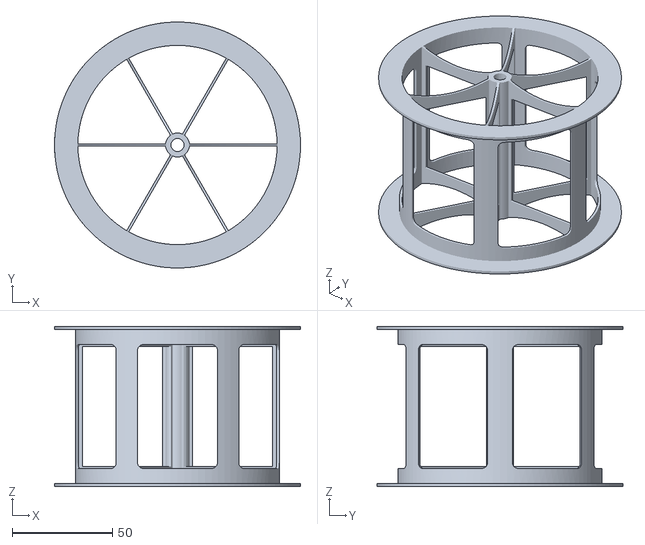
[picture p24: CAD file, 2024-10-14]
hardware/treadmillmain/wheel.stl
123.0 x 123.0 x 80.0

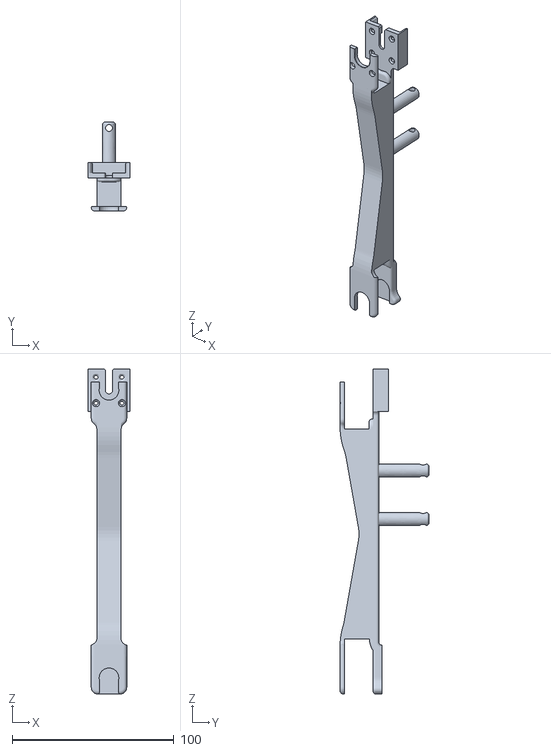
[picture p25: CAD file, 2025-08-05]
hardware/treadwallmain/wall.stl
26.3 x 55.0 x 201.2

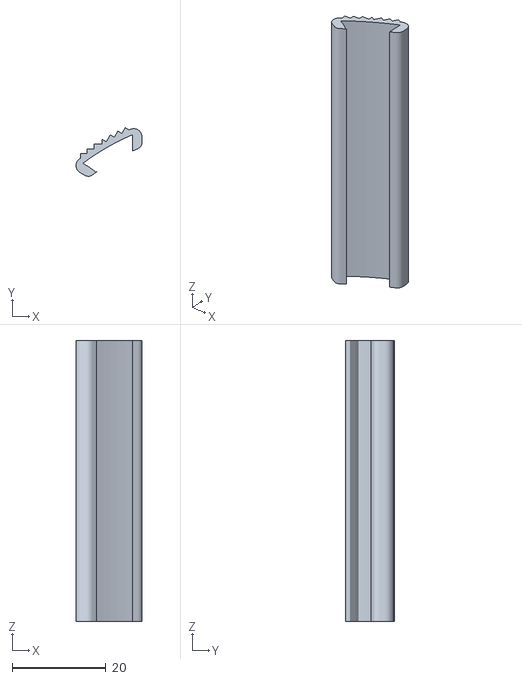
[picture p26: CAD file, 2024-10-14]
hardware/treadmillmain/wheelgummy.stl
14.1 x 10.4 x 60.0

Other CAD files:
hardware/treadwallmain/rack_right.stl
hardware/treadmillmain/rotsensor_holder.stl
hardware/treadwallmain/rack_left.stl
hardware/treadwallmain/motormount_v2.stl
hardware/treadwallmain/piniongear_left.stl
hardware/treadwallmain/wallband_buck.stl
hardware/treadwallmain/wallband_mould.stl

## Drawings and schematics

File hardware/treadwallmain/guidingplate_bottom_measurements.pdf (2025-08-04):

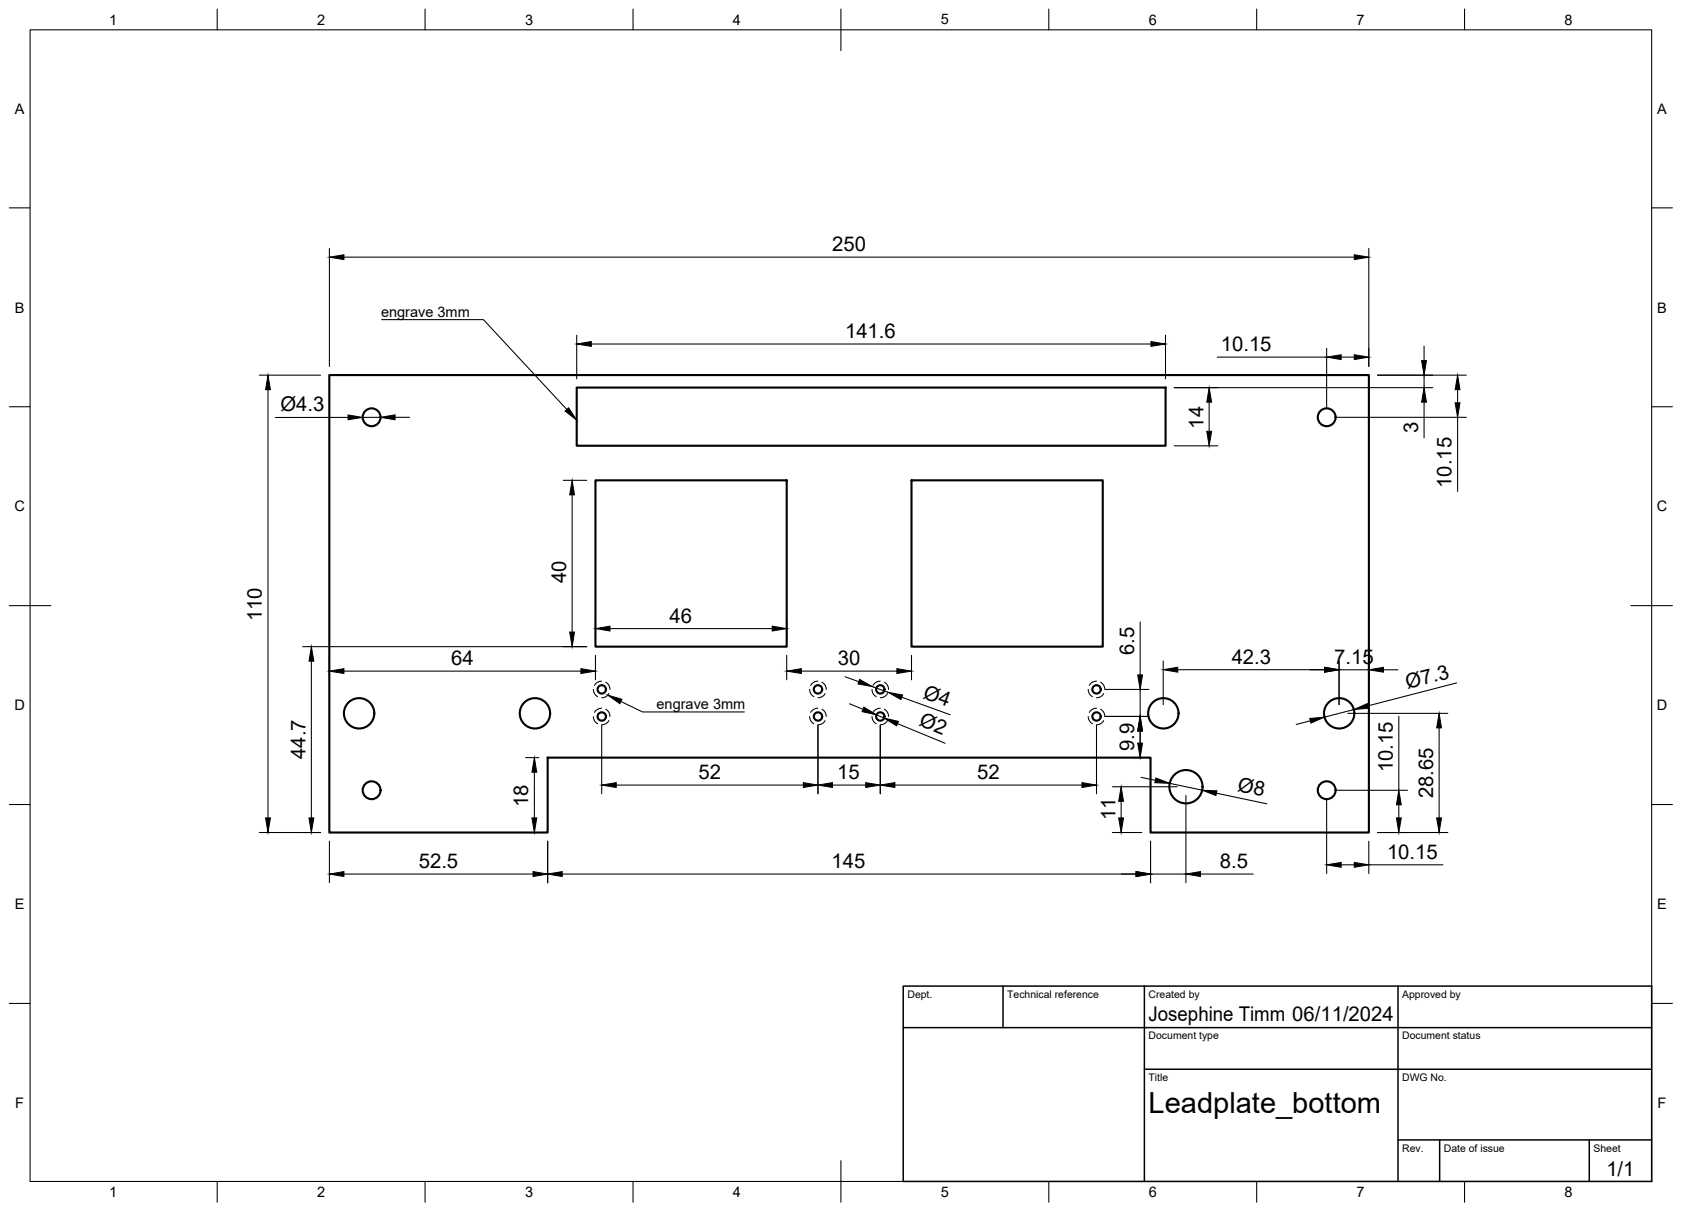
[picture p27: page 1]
Title; DWG No.; Rev.; Date of issue; Sheet; Josephine Timm 110; engrave 3mm

Dept. | Technical reference | Created by 06/11/2024 | Approved by

Document type | Document status

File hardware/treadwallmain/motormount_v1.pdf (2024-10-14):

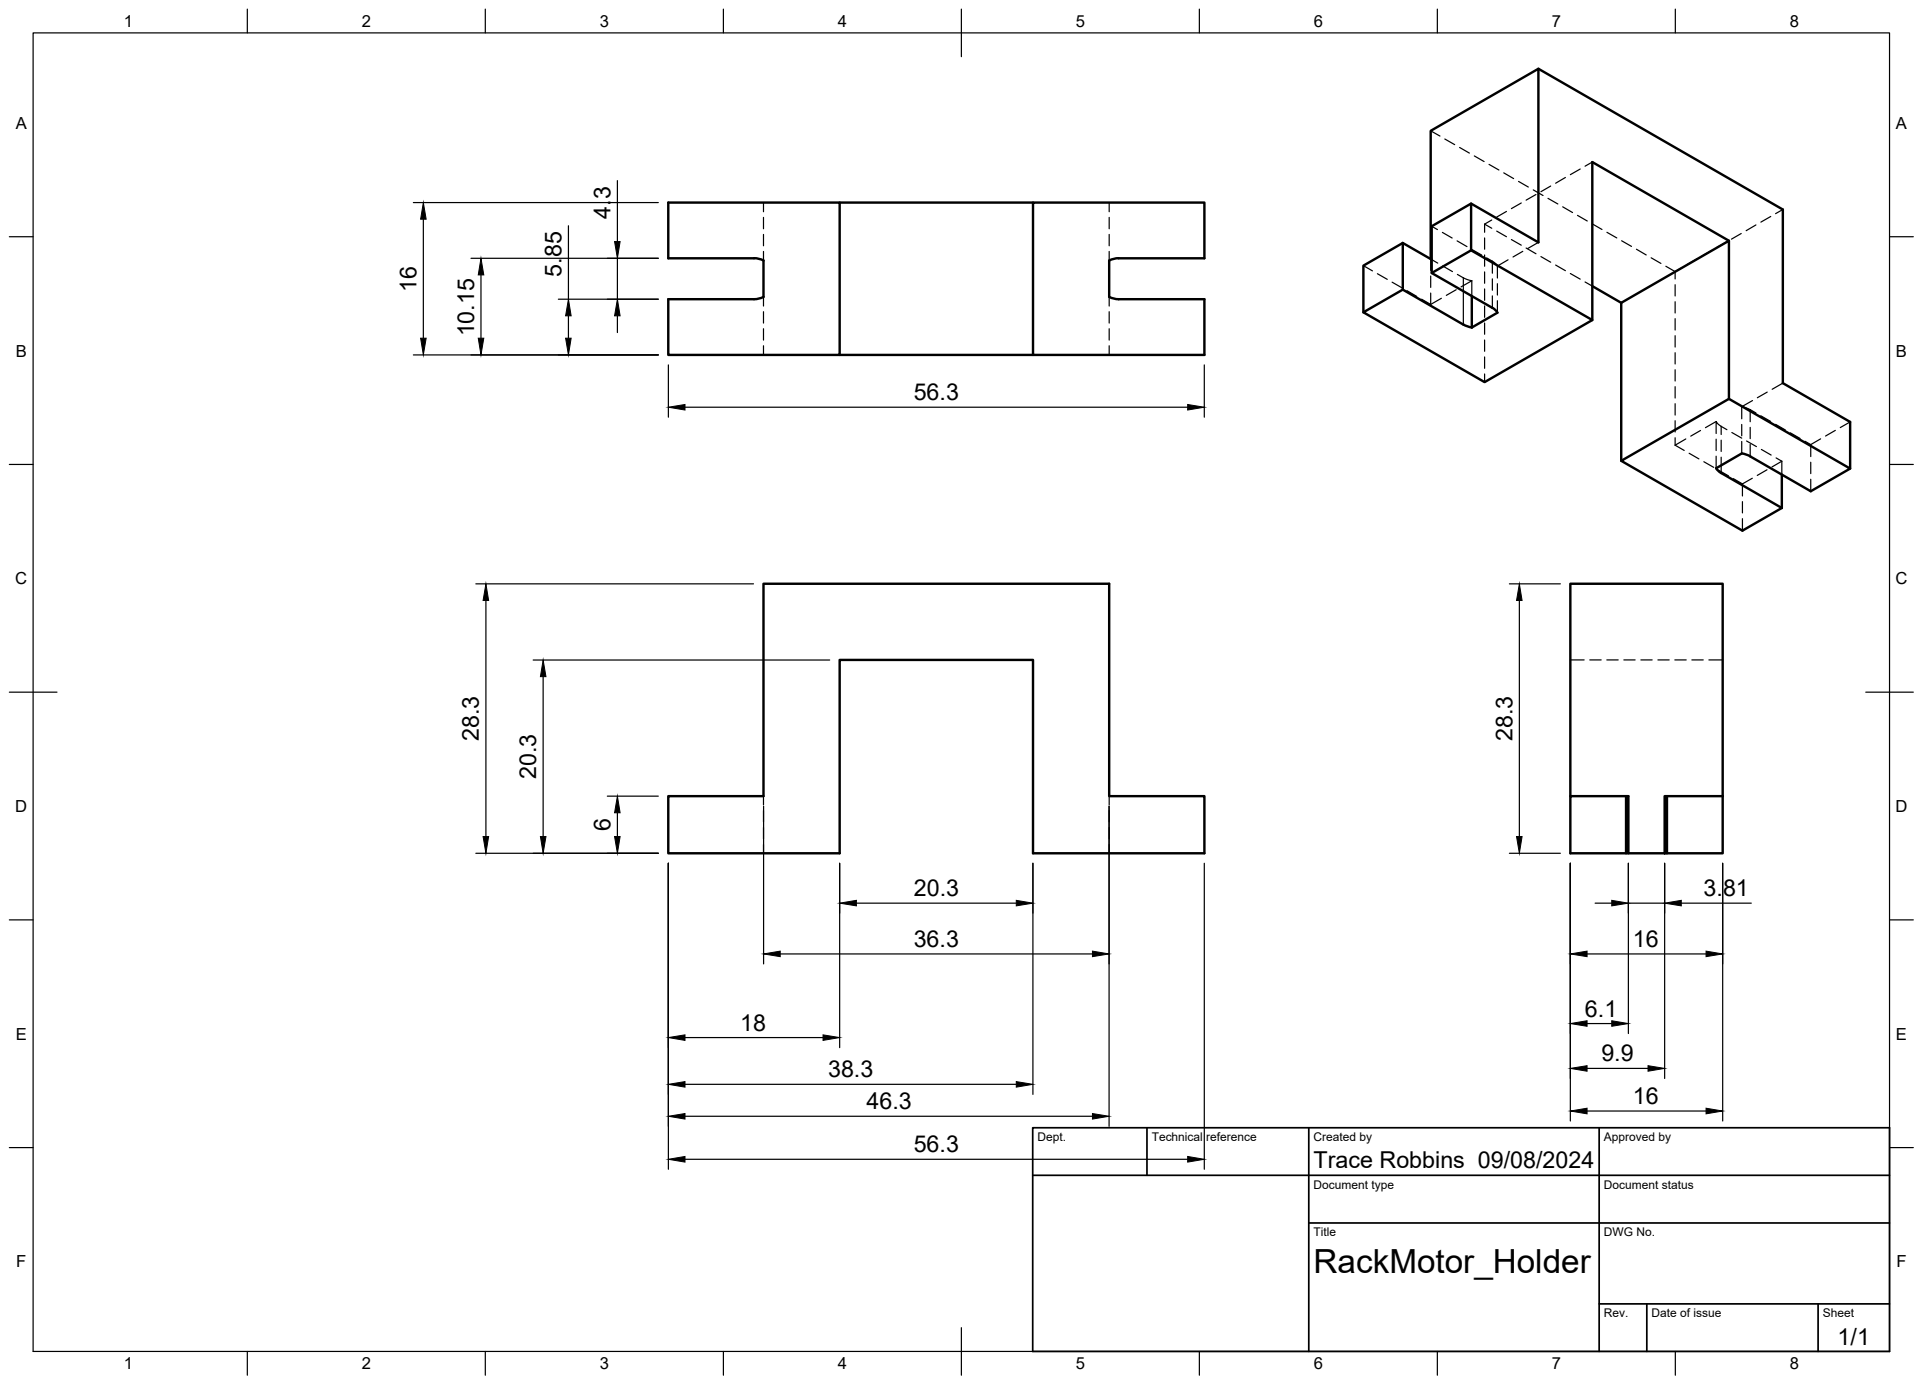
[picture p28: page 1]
Title; DWG No.; Rev.; Date of issue; Sheet

Dept. | Technical reference | Created by Trace Robbins 09/08/2024 | Approved by

Document type | Document status

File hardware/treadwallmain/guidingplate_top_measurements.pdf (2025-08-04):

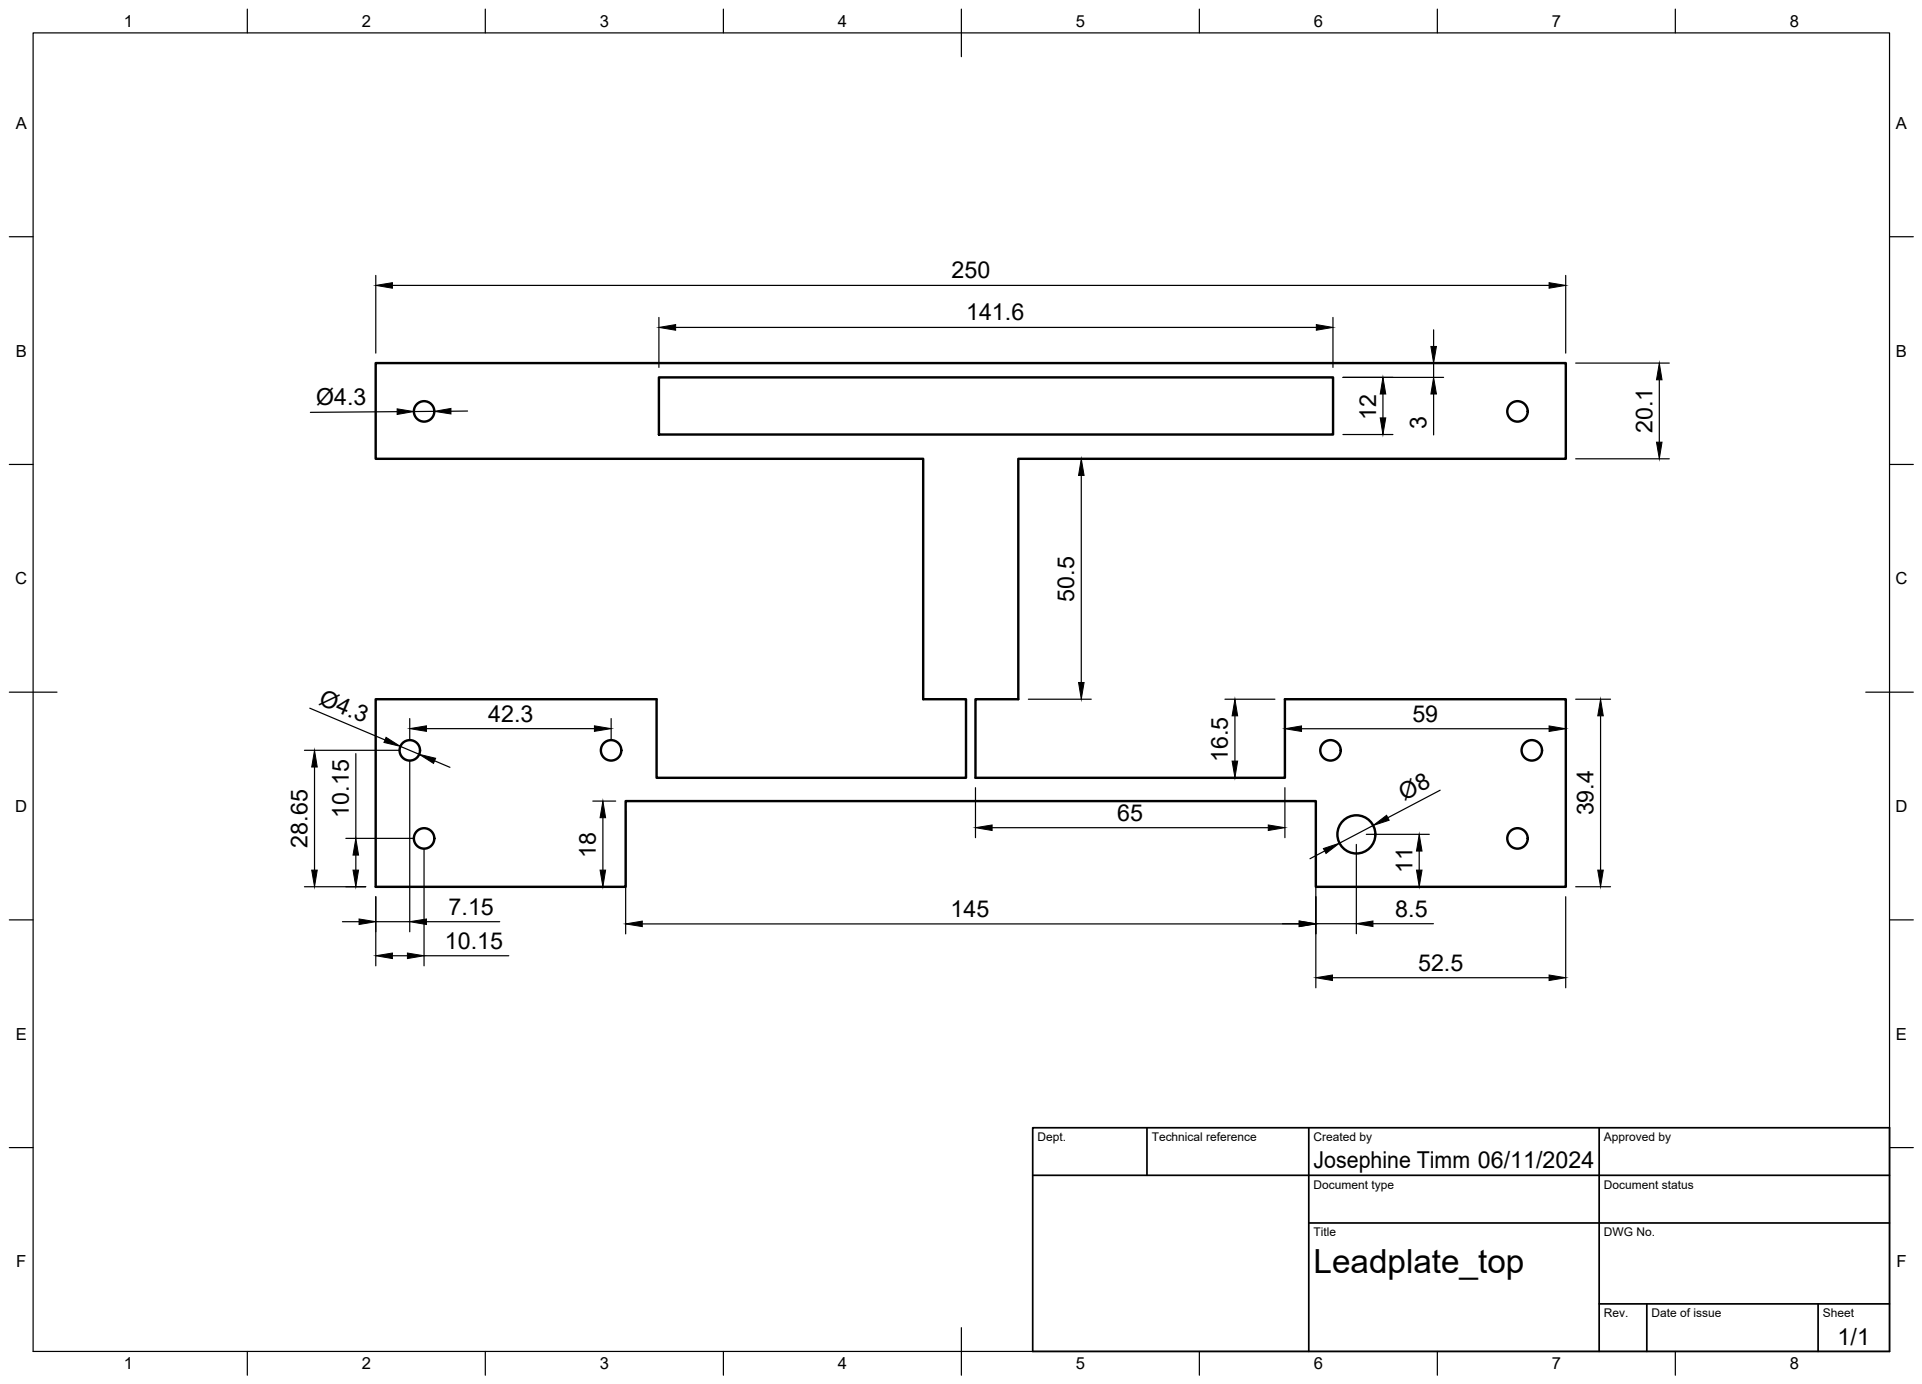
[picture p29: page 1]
Title; DWG No.; Rev.; Date of issue; Sheet

Dept. | Technical reference | Created by Josephine Timm 06/11/2024 | Approved by

Document type | Document status

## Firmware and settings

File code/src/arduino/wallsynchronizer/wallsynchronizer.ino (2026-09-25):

#include <Tic.h>
#include <SoftwareSerial.h>

// Tic Setup
SoftwareSerial tic_serial(10, 11); //pin 10 to Driver TX; pin 11 to Driver RX
TicSerial tic1(tic_serial, 14);
TicSerial tic2(tic_serial, 15);

// Constants
//    Arduino pins:
#define ANALOG_DATA_STREAM_PIN A0
#define ENC_A_PIN 2 //Encoder A - Arduino pin 2 to Black
#define ENC_B_PIN 4 //Encoder B - Arduino pin 4 to White
#define SPEED_PIN 3
//    Serial config:
#define BAUD 115385
#define ANRES 12
//    Data Stream:
#define FW 1 //forwards
#define BW -1 //backwards
#define RUNNING_TIMEOUT 5000
#define TIC_REARM_INTERVAL_MS 500 //slow blind re-arm; catches a late/re-powered driver in ~0.5 s
#define MAX_RUNNING_SPEED 1 //in m/s
#define MIN_RUNNING_SPEED (MAX_RUNNING_SPEED*-1)
#define MAX_PWM_VALUE 4095 //Value to generate 5V with PWM
#define PWM_BASELINE 2045
//    Rotary Encoder, Motor specs:
#define N_STEPS 1024 //Rotary Encoder: number of steps per rotation
#define STEPS_PER_REVOLUTION 200 //Steppers
#define MICROSTEPS_PER_STEP 2 //Steppers
//    Setup measurements:
#define WALL_WHEEL_CIRCUMFERENCE (109*1000) //in microns (1mm is 1000 microns), of the roller wheel
#define WHEEL_RADIUS (53*1000) //wheel radius in microns (1mm is 1000 microns)
#define WHEEL_CIRCUMFERENCE ((float)WHEEL_RADIUS*2*PI)
#define DISTANCE_PER_STEP ((float)WHEEL_CIRCUMFERENCE/N_STEPS)

// Variables
int pwm_output = PWM_BASELINE;
volatile bool detect_change = false;
volatile int direction = 0;
volatile static float total_distance_in_mm = 0.00;
volatile static float current_speed = 0.00;
static int previous_target_velocity = 0;
int target_velocity = 0;
float speed_multiplier = 1.0;
//    Time variables
volatile uint32_t wall_start_time = 0;  //Timestamp for wall movement start
volatile uint32_t sample_start_time = 0;
volatile uint32_t sample_stop_time = 0;
volatile uint32_t elapsed_time = 0;
uint32_t time_no_change = 0;
uint32_t elapsed_time_no_change = 0;
uint32_t last_rearm_time = 0;
//    Scaling
volatile uint32_t pulse_start = 0;
volatile uint32_t pulse_width = 0;
volatile bool new_pulse = false;
volatile float scale_factor = 1.0; // Default scaling factor

// Sends a "Reset command timeout" command to the Tic.
void reset_command_timeout() {
  tic1.resetCommandTimeout();
  tic2.resetCommandTimeout();
}

// Blindly re-arms both Tics so hardware power-up order (and mid-session driver
// power-cycles) don't matter. Energizing + exiting safe start is idempotent: a
// no-op on a Tic that is already running, and the recovery step for one that just
// powered up in safe start. Re-asserts the current target so a freshly-powered
// Tic resumes the correct speed instead of sitting at 0 (synch_walls() otherwise
// only sends a target when it changes).
void rearm_tics() {
  tic1.energize();
  tic1.exitSafeStart();
  tic2.energize();
  tic2.exitSafeStart();
  tic1.setTargetVelocity(previous_target_velocity);
  tic2.setTargetVelocity(previous_target_velocity * -1);
}

// Delays for the specified number of milliseconds while resetting the Tic's command timeout so that its movement does not get interrupted.
void delay_while_resetting_command_timeout(uint32_t ms) {
  uint32_t start = millis();
  do {
    reset_command_timeout();
  } while ((uint32_t)(millis()-start) <= ms);
}

float mapfloat(float x, float in_min, float in_max, float out_min, float out_max) {
  return (x-in_min) * (out_max-out_min) / (in_max - in_min) + out_min;
}

void measure_rotations() {
  detect_change = true;
  if (digitalRead(ENC_A_PIN) == digitalRead(ENC_B_PIN)) {
  direction = FW;
  } else {
  direction = BW;
  }
  total_distance_in_mm += DISTANCE_PER_STEP/1000;
  sample_stop_time = micros(); //in ms
  elapsed_time = sample_stop_time-sample_start_time;
  sample_start_time = sample_stop_time;
  current_speed = (float)DISTANCE_PER_STEP/elapsed_time*direction; //in microm/micros
}

int calculate_target_velocity(float speed) {
  if (Serial.available()){
    String input = Serial.readStringUntil('\n');
    speed_multiplier = input.toFloat();
  }
  speed = speed*speed_multiplier;

  // Calculate Wall-Wheel revolutions per second (based on treadmill speed)
  float wheel_revolutions_per_second = (speed*1000000)/WALL_WHEEL_CIRCUMFERENCE;
  // Convert Wall-Wheel revolutions to motor steps per second
  float motor_steps_per_second = wheel_revolutions_per_second*STEPS_PER_REVOLUTION;
  // Convert steps to microsteps per second
  float microsteps_per_second = motor_steps_per_second*MICROSTEPS_PER_STEP;

  return microsteps_per_second*10000;
}

void synch_walls() {
  if (detect_change == true) {
    target_velocity = calculate_target_velocity(current_speed);
    if (target_velocity != previous_target_velocity) {
      tic1.setTargetVelocity(target_velocity);
      tic2.setTargetVelocity(target_velocity*-1);
      previous_target_velocity = target_velocity;

      wall_start_time = micros();  // Record wall movement start time
      uint32_t delay = (wall_start_time - sample_stop_time)/1000;
      //Serial.print("Delay (ms): ");
      //Serial.println(delay);  // Log the delay in milliseconds
    }
    detect_change = false;
  } else if (detect_change == false) {
    time_no_change = micros();
    elapsed_time_no_change = time_no_change-sample_start_time;
    if (elapsed_time_no_change > RUNNING_TIMEOUT && time_no_change > sample_stop_time) {
      current_speed=0.00;
      direction = 0;
      detect_change=true;
    }
  }
}

void stream_data() {
  //pwm_output = mapfloat(current_speed, MIN_RUNNING_SPEED, MAX_RUNNING_SPEED, 0, MAX_PWM_VALUE);
  //pwm_output = constrain(pwm_output, 0, MAX_PWM_VALUE);
  //analogWrite(SPEED_PIN, pwm_output);

  Serial.println(current_speed);
  Serial.println(target_velocity);
  //Serial.print(",");
  //Serial.print(pwm_output);
  //Serial.print(",");
  //Serial.println(total_distance_in_mm);
}


void setup() {
  //tic_serial.begin(9600);
  tic_serial.begin(BAUD);
  //Serial.begin(9600);
  Serial.begin(BAUD);
  analogWriteResolution(ANRES);

  pinMode(ENC_A_PIN, INPUT_PULLUP);
  pinMode(ENC_B_PIN, INPUT_PULLUP);
  //pinMode(SPEED_PIN, OUTPUT);
  //pinMode(ANALOG_DATA_STREAM_PIN, OUTPUT);

  // Arm both Tics if they're already powered. If they're not, rearm_tics() in
  // loop() will pick them up whenever they come online, so startup order and
  // mid-session driver power-cycles don't matter.
  rearm_tics();

  attachInterrupt(digitalPinToInterrupt(ENC_A_PIN), measure_rotations, RISING);
  sample_start_time = micros();
}

void loop() {
  synch_walls();
  //stream_data();
  reset_command_timeout();
  if ((uint32_t)(millis() - last_rearm_time) >= TIC_REARM_INTERVAL_MS) {
    rearm_tics();
    last_rearm_time = millis();
  }
}

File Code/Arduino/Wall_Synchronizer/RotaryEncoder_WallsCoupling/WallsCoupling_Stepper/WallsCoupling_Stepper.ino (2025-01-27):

#include <Tic.h>
#include <SoftwareSerial.h>

// Tic Setup
SoftwareSerial ticSerial(10, 11); //pin 10 to Driver TX; pin 11 to Driver RX
TicSerial tic1(ticSerial, 14);
TicSerial tic2(ticSerial, 15);

// Constants
//    Arduino pins:
#define AnalogDataStreamPin A0
#define encAPin 2 //Encoder A - Arduino pin 2 to Black
#define encBPin 4 //Encoder B - Arduino pin 4 to White
//    Data Stream:
#define FW 1 //forwards
#define BW -1 //backwards
#define RunningTimeout 5000
#define MaxRunningSpeed 1 //in m/s
#define MinRunningSpeed (MaxRunningSpeed*-1)
#define MaxPWMValue 4095 //Value to generate 5V with PWM
#define pwmBaseline 2045
//    Rotary Encoder, Motor specs:
#define nSteps 1024 //Rotary Encoder: number of steps per rotation
#define StepsperRevolution 200 //Steppers
#define MicrostepsPerStep 1 //Steppers
//    Setup measurements
#define WallWheelCircumference (109*1000) //in microns (1mm is 1000 microns), of the roller wheel
#define wheelRadius (53*1000) //wheel radius in microns (1mm is 1000 microns)
#define wheelCircumference ((float)wheelRadius*2*PI)
#define DistancePerStep ((float)wheelCircumference/nSteps) 

// Variables
int pwmOutput = pwmBaseline;
volatile bool DetectChange = false;
volatile int Direction = 0;
volatile static float TotalDistanceInMM = 0.00;
volatile static float CurrentSpeed = 0.00;
static int previousTargetVelocity = 0;
int targetVelocity = 0;
//    Time variables
volatile uint32_t WallStartTime = 0;  //Timestamp for wall movement start
volatile uint32_t SampleStartTime = 0; 
volatile uint32_t SampleStopTime = 0;
volatile uint32_t ElapsedTime = 0;
uint32_t TimeNoChange = 0;
uint32_t ElapsedTimeNoChange = 0;

// Sends a "Reset command timeout" command to the Tic.
void resetCommandTimeout() {
  tic1.resetCommandTimeout();
  tic2.resetCommandTimeout();
}

// Delays for the specified number of milliseconds while resetting the Tic's command timeout so that its movement does not get interrupted.
void delayWhileResettingCommandTimeout(uint32_t ms) {
  uint32_t start = millis();
  do
  {
    resetCommandTimeout();
  } while ((uint32_t)(millis()-start) <= ms);
}

float mapfloat(float x, float in_min, float in_max, float out_min, float out_max) {
  return (x-in_min) * (out_max-out_min) / (in_max - in_min) + out_min;
}

void MeasureRotations() {
  DetectChange = true;
  if (digitalRead(encAPin) == digitalRead(encBPin)) {
  Direction = FW;
  } else {
  Direction = BW;
  }
  TotalDistanceInMM += DistancePerStep/1000;
  SampleStopTime = micros(); //in ms
  ElapsedTime = SampleStopTime-SampleStartTime;
  SampleStartTime = SampleStopTime;
  CurrentSpeed = (float)DistancePerStep/ElapsedTime*Direction; //in microm/micros 
}

int calculateTargetVelocity(float speed) {
  // Calculate Wall-Wheel revolutions per second (based on treadmill speed)
  float wheelRevolutionsPerSecond = (speed*1000000)/WallWheelCircumference;
  // Convert Wall-Wheel revolutions to motor steps per second
  float motorStepsPerSecond = wheelRevolutionsPerSecond*StepsperRevolution;
  // Convert steps to microsteps per second
  float microstepsPerSecond = motorStepsPerSecond*MicrostepsPerStep;
  
  return microstepsPerSecond*10000;
}

void SynchWalls() {
  if (DetectChange == true) {
    targetVelocity = calculateTargetVelocity(CurrentSpeed);
    if (targetVelocity != previousTargetVelocity) {
      tic1.setTargetVelocity(targetVelocity);
      tic2.setTargetVelocity(targetVelocity*-1);
      previousTargetVelocity = targetVelocity;

      WallStartTime = micros();  // Record wall movement start time
      uint32_t delay = (WallStartTime - SampleStopTime)/1000;
      Serial.print("Delay (ms): ");
      Serial.println(delay);  // Log the delay in milliseconds
    }
    DetectChange = false;
  } else if (DetectChange == false) {
    TimeNoChange = micros();
    ElapsedTimeNoChange = TimeNoChange-SampleStartTime;
    if (ElapsedTimeNoChange > RunningTimeout && TimeNoChange > SampleStopTime) {
      CurrentSpeed=0.00;
      Direction = 0;
      DetectChange=true;
    }
  }
}

void StreamData() {
  pwmOutput = mapfloat(CurrentSpeed, MinRunningSpeed, MaxRunningSpeed, 0, MaxPWMValue);
  pwmOutput = constrain(pwmOutput, 0, MaxPWMValue);
  analogWrite(AnalogDataStreamPin, pwmOutput);

  //Serial.print(CurrentSpeed);
  //Serial.print(",");
  //Serial.print(pwmOutput);
  //Serial.print(",");
  //Serial.println(TotalDistanceInMM);
}


void setup() {
  //ticSerial.begin(9600);
  ticSerial.begin(115385);
  //Serial.begin(9600);
  //Serial.begin(115385);
  analogWriteResolution(12);

  pinMode(encAPin, INPUT_PULLUP);
  pinMode(encBPin, INPUT_PULLUP);
  //pinMode(AnalogDataStreamPin, OUTPUT);

  // Give the Tic some time to start up.
  delay(20);
  // Tells the Tic that it is OK to start driving the motor.
  tic1.exitSafeStart();
  tic2.exitSafeStart();

  attachInterrupt(digitalPinToInterrupt(encAPin), MeasureRotations, RISING);
  SampleStartTime = micros();
}

void loop() {
  SynchWalls();
  StreamData();
  resetCommandTimeout();
}

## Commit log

2024-05-22 walls coupling with servo or steppe motor
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2024-05-28 plays constant voltage during stimulus state
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2024-06-26 add homing in setup
2024-07-29 add homing in between trials
2024-09-27 convert Voltage to Distance
    Comment: still not correctly mapped
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2024-10-14 upload stl files
    [Ball_ Bearing_Holder.stl, Motorized_Roller.stl, Passive_Roller.stl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]
2024-11-04 Update Treadwall.m
    comment currently not working parts
2024-11-05 rename files
    [sensor_data.xlsx]
2024-11-05 create sensor_data
    [sensor_data_left.xlsx, sensor_data_right.xlsx]
2024-11-25 creating triallist on the run (currently all distances and all offsets)
2024-12-06 Update Distance_Sensor.ino
    adjust tuning curve values and added interpolation of distance. pwmStream is still not properly displaying the distance and values have to be adjust to final tuning curve
2024-12-06 create csv files for future loading via arduino
    [sensor_data_left.csv.csv, sensor_data_right.csv.csv]
2024-12-10 adjust hardcoded values
    note: still wavesurfer only measuring 0 or 5 volts
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2025-01-10 update files to print
    [Motorized_Roller.stl, Passive_Roller.stl, Tension_Roller.stl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]
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2025-01-13 Create log_data.py
    new approach of automatically tuning distance sensors. Currently with error: cannot convert string to float
    [log_data.py]
2025-01-22 clean up Tuning Folders
    [sensor_data.xlsx, sensor_data_left.csv.csv, sensor_data_left.xlsx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]
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2025-02-05 Create WallsCoupling_Stepper_V2.ino
    works via Bpod rotary encoder module V2, scaling not yet tested
2025-02-06 smoothed out movement
    -> issues if rotary encoder moves one round quicker than Arduino is measuring
2025-02-06 add rotary encoder module
    will be used for future synching
2025-02-07 Add Pulse Width detection for scaling
    approach in general works however motor movement now less smooth than before
2025-02-11 Update Treadwall_predictable.m
    Two Tests:
    -> pulses for speed scaling
    -> fixed voltages for lateral movement
2025-02-13 add thresholds for changing width
    -> global timer for exiting loop
    -> still have to figure out correct thresholds
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2025-05-14 update for new guiding plate
    there seems to be still some mismatch with the real distance
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2025-06-27 save tic settings
    for the synchronizer right side the device number has to be changed to 15
2025-06-30 moved to old_Protocols
    [triallist.csv]
2025-06-30 create testing protocol
    [triallist_testing.csv]
2025-07-01 start writing habituation protocols
    [triallist_h1.xlsx, triallist_h2.xlsx]
2025-07-02 update habituation protocols
    [triallist_h1.xlsx, triallist_h2.xlsx]
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2025-07-03 update habituation protocols
    analog input changes in 0.5V steps
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2025-07-09 Update VideoAquisition.py
    no missing frames
2025-07-10 Update VideoAquisition.py
    - if trigger stops no frames missing
    - if stop signal received -> missing two frames most likely at the end
2025-07-10 add direct speed readout (as PWM signal on pin 3)
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2025-07-11 serial communication between computer and arduino in between trials
2025-07-28 Update Treadwall_scrambled.m
    added scaling and smooth camera stop
2025-08-05 update racks
    [Rack_Left.stl, Rack_Right.stl]
2025-08-13 zone transition with reflective sensor feedback
    currently only works in one direction
2025-08-14 Update Treadwall_predictable.m
    flexible can switch between forward and backwards running
2025-08-15 update habituation protocols
    add scaling and smooth camera stop
2025-08-15 Update Treadwall_predictable.m
    working on timer, still not functional
2025-08-18 Update Treadwall_predictable.m
    fixed timer and rot-thresholds, still to be tested
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2025-08-25 add stl files for boxes
    [Bottom.stl, Mover_Box.stl, Synchronizer_Box.stl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]
2025-10-06 update USB Stream
    -> rotary encoder USB stream now starts after restarting timer
2025-10-16 TriggerMode = Master
    - to prevent premature moving of walls
    - waveform longer than needed and interrupted from next one
2026-01-14 update COM handling
    - include error message if COMs are connected in the wrong way
    - this way COMs can quickly be tried out with the Bpod Console
    - only Arduino COM needs to be updated in the script
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2026-04-01 Update CapacitiveSensorRotaryChangedSensity.ino
    - adapt delays -> 'calibrated pump'
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2026-04-14 Update Treadwall_predictable.m
    - fixed timer deletion
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2026-05-13 Update VideoAquisition.py
    - save frames in chunks
    - save to fast disk
    - smooth live stream
    - save timestamps in txt file and as npy for each chunk
2026-06-09 Copy VideoAquisition.py
    - single camera video aquisition pipeline
2026-06-09 Update VideoAquisition.py
    - two cameras
    - both cameras save single frames
    - have to be connected to different USB hubs
    - second camera three running
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2026-06-13 update GUI
    - add matlab log
    - add bpod state
    - add bpod disconnect button
    - notes in new lines
2026-08-20 fixed rotary encoder data name
2026-08-20 clean camera exit
    - fixed bug when emergency stop while waiting for wavesurfer where cameras were not released
2026-08-20 fix empty video file bug
    - only save video if frames arrive
2026-08-21 update GUI
    - disconnect and reconnect bpod possible
    - free matlab when closing GUI
    - flag parameters as unausable
    - buttons and parameters only usable if needed
    - option of manually adding animal ID
2026-09-10 reorder (TO BE TESTED)
    - reorder code structure
    - update references
    - add submodules
    [triallist_testing.csv]
2026-09-11 clean and rename hardware
    - some files still need to be checked
    - READMEs have to be updated
    [MotorMount.stl, Wall.stl, Wall_V2.2.step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]
2026-09-11 reorg: normalize path casing to lowercase code/ (record case-only renames)
    [triallist_testing.csv]
2026-09-14 added parameters to config
    - arduino parameters in README
    - cam parameters in config
    - GUI parameters in config
    - add additional files for tic and cam settings
2026-09-15 hardware cleanup
    - delete unnecessary PCB files
    - rename files
    - check current stl files (-> all up to date)
    [Wall_V2.2.step, motormount_v2.stl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]
2026-09-16 rename and reorg
    [tension_holder.stl, tension_roller.stl]
2026-09-16 update assembly
    - update assembly videos with new parts
    - add assembly picture with platform
2026-09-16 update arduino constants
    - all capital letters
    - variables: all lower case
2026-09-17 fixed safe start bug
    on wrong order startup tics of synchronizer never exited save start modus -> fixed
    [lickport.ino, wallsynchronizer.ino]
2026-09-17 fixed homing bug
    The right wall was homing in the wrong direction from time to time. Switched back blue and brown wire to default wiring and adapted tic settings so movement is still correct.
    Has to be used to see if this fixed the bug
2026-09-24 add analog in trigger to all protocols
    - input from reflective sensor
    - recorded as sanity check for binning
2026-09-25 fixed stale frontcam frames
2026-09-25 add camera stop delay to main config (shared over protocols)
